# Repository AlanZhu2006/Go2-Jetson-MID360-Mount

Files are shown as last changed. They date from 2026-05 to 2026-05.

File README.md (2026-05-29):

# Unitree Go2 + Jetson Livox MID-360 Top Mount  
# 宇树 Unitree Go2 加装 Jetson 版本 Livox MID-360 顶部支架

[English](#english) | [中文](#中文)

---

## English

### Overview

This repository provides a 3D-printable top mounting bracket for installing a **Livox MID-360 LiDAR** on a **Unitree Go2 with an added Jetson module**.

Unlike many back-deck mounting solutions, this design places the MID-360 **above the Go2 head / front-top area**. The purpose is to keep the LiDAR dome higher and more exposed, so that the sensor has a better surrounding view and is less blocked by the Go2 body, Jetson module, power cables, USB/Ethernet adapters, and other onboard devices.

This mount is designed for robotics experiments such as:

- LiDAR SLAM / LIO
- Go2 navigation and localization
- MID-360 data collection
- Jetson onboard perception experiments
- real-robot deployment where the original rear/top deck is already occupied by Jetson or other electronics

> This is a community/open-source mechanical adapter, not an official Unitree or Livox product. Please verify hole positions, screw length, clearance, and mechanical strength on your own robot before operation.

---

### Images

#### Full installation overview

Place the full robot photo here:

```markdown
![Full installation overview](media/go2_mid360_jetson_overview.jpg)
```

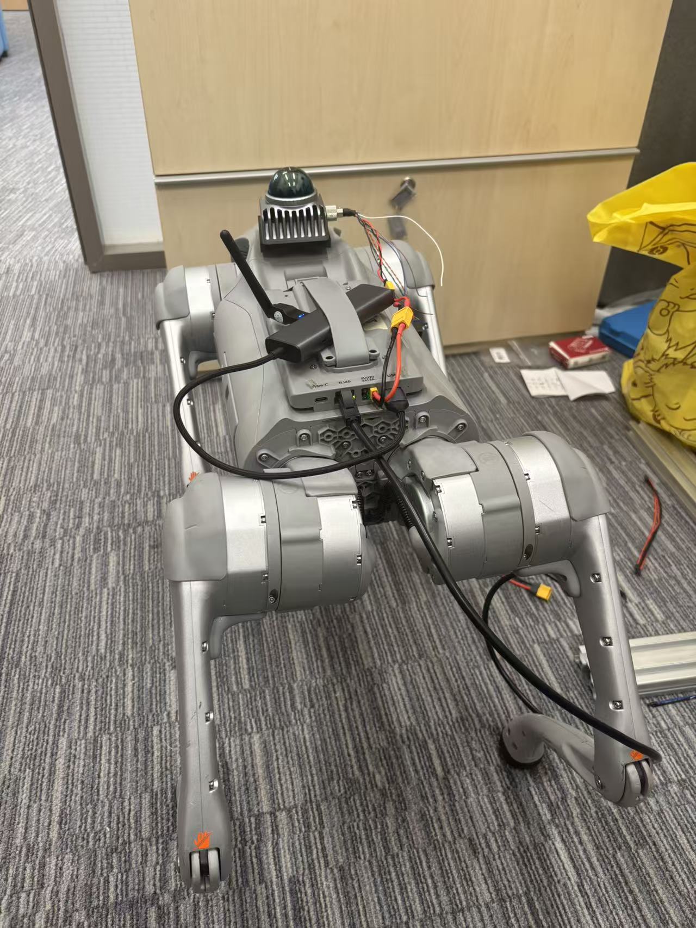
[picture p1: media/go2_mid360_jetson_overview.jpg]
Full installation overview


#### CAD / hole-layout preview

Place the top-down CAD / hole-layout preview here:

```markdown
![Top-down CAD preview](media/topdown_slot_preview.png)
```

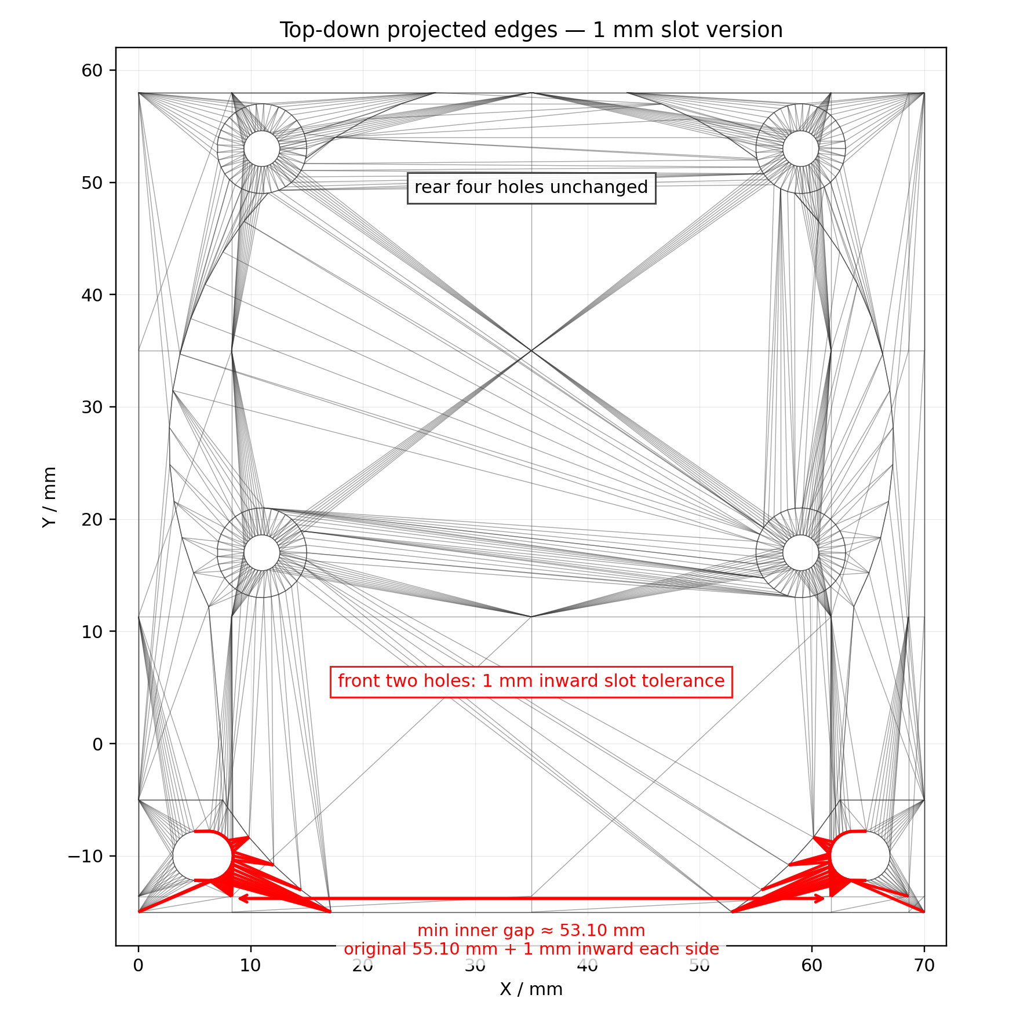
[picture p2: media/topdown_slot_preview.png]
Top-down CAD preview


---

### Design motivation

Many MID-360 mounts for Unitree Go2 assume that the top/back platform is mostly clean. In the **Go2 EDU / Jetson-added configuration**, however, the upper body area is often already occupied by:

- a Jetson module
- power cables
- USB/Ethernet adapters
- XT connectors
- network modules or additional electronics

A rear-mounted MID-360 may therefore be partially blocked by the Jetson or cable bundle. This design moves the sensor to the **front-top/head area**, with the goal of preserving a more useful LiDAR field of view for SLAM, localization, and navigation.

---

### Mechanical design

The bracket follows a simple mechanical logic:

1. **Four MID-360 mounting holes**  
   The four main holes on the upper mounting plate correspond to the MID-360 mounting pattern. They are intended for M3 screws used to fasten the MID-360 to the printed bracket.

2. **Two Go2 front mounting holes**  
   The two front holes correspond to the existing threaded holes on the top/front area of the Unitree Go2 body. These holes are used to fix the bracket to the robot.

3. **1 mm inward slot tolerance**  
   The two Go2-side front holes are designed as short inward slots instead of perfect circular holes. Each side has about 1 mm inward tolerance. This compensates for real measurement error, 3D-printing shrinkage, and small manufacturing differences between robots.

4. **Rear four holes unchanged**  
   The four MID-360 mounting holes should remain unchanged unless you intentionally redesign the LiDAR-side mounting pattern.

5. **Top-mounted sensor placement**  
   The MID-360 is placed above the Go2 head/front-top region to improve visibility and reduce occlusion from the Jetson platform and cables.

---

### Important dimensions and hole logic

| Feature | Description |
|---|---|
| LiDAR-side mounting holes | 4 × M3 clearance holes for Livox MID-360 mounting |
| Robot-side mounting holes | 2 × M3 clearance / short-slot holes for Go2 threaded mounting points |
| Front-hole measured reference | 55.10 mm inner-side reference distance measured on the Go2 body |
| Slot tolerance | 1 mm inward slot tolerance on each of the two front holes |
| Slot purpose | Compensates for printing tolerance and real robot measurement error |
| Rear four holes | Kept unchanged for the MID-360 mounting pattern |

> The 55.10 mm value refers to the measured inner-side distance from the real Go2 body, not the screw center-to-center distance. Do not reinterpret it as center pitch.

---

### Repository structure

Suggested structure:

```text
unitree-go2-jetson-mid360-top-mount/
├── README.md
├── LICENSE
├── cad/
│   └── unitree_go2_jetson_mid360_top_mount.stl
└── media/
    ├── go2_mid360_jetson_overview.jpg
    └── topdown_slot_preview.png
```

| File | Description |
|---|---|
| `cad/unitree_go2_jetson_mid360_top_mount.stl` | Printable STL model of the bracket |
| `media/go2_mid360_jetson_overview.jpg` | Full installation overview photo |
| `media/topdown_slot_preview.png` | Top-down preview showing the hole layout and 1 mm slot tolerance |
| `README.md` | Project documentation |
| `LICENSE` | Open-source license file |

---

### Required hardware

| Part | Quantity | Notes |
|---|---:|---|
| Livox MID-360 | 1 | LiDAR sensor |
| Unitree Go2 with Jetson module | 1 | Target robot platform |
| 3D-printed bracket | 1 | Print from the STL file |
| M3 screws for MID-360 | 4 | Length depends on bracket thickness and MID-360 thread depth |
| M3 screws for Go2 body | 2 | Use appropriate length for the Go2 threaded holes |
| M3 flat washers | 6 | Strongly recommended, especially for the two front slots |
| M3 spring washers or blue threadlocker | optional | Helps prevent loosening under vibration |
| Cable ties / cable clips | optional | For cable routing |

Screw notes:

- Do not use screws that are too long. They may bottom out or damage threads/components.
- For 3D-printed parts, flat washers are strongly recommended to distribute clamping force.
- For the two slotted front holes, washers are especially important because the slots rely on clamping force.

---

### 3D printing settings

Suggested settings:

| Setting | Recommended value |
|---|---|
| Material | PETG, PLA+, ABS, ASA, or PA-CF |
| Layer height | 0.20 mm |
| Walls / perimeters | 4 or more |
| Infill | 35–50% |
| Top/bottom layers | 5 or more |
| Supports | Enable if required by the selected print orientation |
| Brim | Recommended if warping occurs |
| Orientation | Keep the main mounting face flat when possible |

Material suggestions:

- **PETG**: recommended general-purpose option; tougher than standard PLA.
- **PLA+**: easy to print and acceptable for indoor testing, but may creep under long-term load or heat.
- **ASA / ABS**: better heat resistance, but needs a more controlled printing environment.
- **PA-CF / nylon-CF**: stronger and stiffer; recommended for more serious field tests if available.

---

### Assembly instructions

1. **Print the bracket**  
   Print the STL with enough walls and infill. Remove support material and clean the holes if necessary.

2. **Check screw fit before installation**  
   Test all holes with M3 screws before mounting the bracket on the robot. The Go2-side front holes are clearance/slot holes, not threaded holes.

3. **Mount the MID-360**  
   Align the MID-360 with the four LiDAR-side mounting holes. Use 4 × M3 screws to fasten the LiDAR to the bracket. Tighten gradually in a diagonal pattern.

4. **Mount the bracket on the Go2**  
   Align the two front slotted holes with the Go2 top/front threaded holes. Use 2 × M3 screws with flat washers. Adjust the position within the 1 mm slot tolerance, then tighten the screws.

5. **Route the cables**  
   Route the MID-360 power/data cable toward the Jetson or onboard computer. Avoid tight bending and avoid pulling on the LiDAR connector.

6. **Check clearance**  
   Make sure the mount does not collide with the Jetson module, Go2 body shell, head/front cover, cables, emergency stop, or other accessories.

7. **Static vibration check**  
   Before walking the robot, gently shake the mount by hand. If there is visible movement, tighten the screws, add washers, or improve the print quality.

8. **Low-speed walking test**  
   Start with standing or low-speed walking tests. Re-check all screws after the first few minutes of motion.

---

### Notes for SLAM / localization

After mechanical installation, the LiDAR frame still needs to be configured correctly in software.

Recommended checks:

- Verify the MID-360 coordinate-frame orientation.
- Measure or estimate the LiDAR-to-base transform.
- Publish the correct TF, for example `base_link -> mid360`.
- Make sure the MID-360 is approximately level when the Go2 is standing in its normal posture.
- Keep cables away from the LiDAR dome.
- Re-check extrinsics if the mount is removed and reinstalled.

For FAST-LIO, LIO-SAM, or other LIO systems, inaccurate extrinsics may cause drift, tilted maps, or unstable odometry even if the physical mount is rigid.

---

### Why the front holes use 1 mm slots

The Go2-side hole position is based on a real caliper measurement. Since 3D printing and robot shell tolerances can introduce small errors, perfectly circular holes may fail even when the CAD model looks correct.

This design uses a **1 mm inward slot tolerance** on each of the two front holes. Compared with a 2 mm slot, a 1 mm slot is more rigid and less likely to slip, while still providing useful assembly tolerance.

Use M3 flat washers to increase contact area and improve clamping stability.

---

### Safety warning

- Do not operate the Go2 at high speed before the mount is fully tested.
- Re-check all screws after walking tests.
- Use cable ties to prevent cables from entering joints or legs.
- Do not overtighten screws into plastic or threaded holes.
- Do not block the MID-360 dome.
- Protect the LiDAR from impact during falls or collisions.

---

### License

Recommended licenses:

- **MIT License**: simple and permissive.
- **CERN-OHL-S v2**: suitable for open-source hardware.
- **CC BY 4.0**: suitable if you mainly want attribution for CAD/images.

For a mechanical open-source hardware project, **CERN-OHL-S v2** or **MIT License** is recommended.

---

### Disclaimer

This project is provided as-is, without warranty. The author is not responsible for damage to robots, sensors, printed parts, or surrounding objects. Always verify mechanical fit, screw length, cable routing, and sensor safety before operating the robot.

---

## 中文

### 项目简介

本仓库提供一个可 3D 打印的 **Unitree Go2 加装 Jetson 版本 Livox MID-360 顶部安装支架**。

这个支架用于把 **Livox MID-360 激光雷达** 安装在 **宇树 Unitree Go2 头部 / 前上方区域**。相比安装在后背平台的方案，这个设计会让 MID-360 的圆顶更高、更靠前，从而减少 Go2 机身、Jetson 模块、电源线、USB / 网口转接器和其他设备对雷达视野的遮挡。

适用场景包括：

- 激光雷达 SLAM / LIO
- Go2 实机导航与定位
- MID-360 数据采集
- Jetson 机载感知实验
- 后背平台已经被 Jetson 或其他电子设备占用的 Go2 改装方案

> 这是一个社区开源机械适配件，不是 Unitree 或 Livox 官方产品。实机运行前请务必检查孔位、螺丝长度、安装强度、空间干涉和线缆安全。

---

### 图片展示

#### 完整安装效果图

在这里插入完整全貌图：

```markdown
![完整安装效果图](media/go2_mid360_jetson_overview.jpg)
```

完整安装效果图

#### CAD / 孔位预览图

在这里插入顶视孔位预览图：

```markdown
![孔位预览图](media/topdown_slot_preview.png)
```

孔位预览图

---

### 设计动机

很多 Unitree Go2 的 MID-360 支架默认机身上方或后背平台比较干净。但在 **Go2 EDU / 加装 Jetson** 的配置下，机器人上方往往已经有：

- Jetson 模块
- 电源线
- USB / 网口转接器
- XT 接头
- 通信模块或其他电子设备

如果 MID-360 继续安装在后背或较低位置，雷达可能会被 Jetson、线缆或机身结构部分遮挡。因此本设计把 MID-360 移到 **Go2 头部上方 / 前上方**，目标不是单纯固定雷达，而是尽量保证 SLAM、定位和导航所需的雷达视野。

---

### 机械设计说明

支架的设计逻辑如下：

1. **四个 MID-360 安装孔**  
   上方安装板上的四个孔对应 MID-360 的安装参数，用于通过 M3 螺丝把 Livox MID-360 固定到 3D 打印支架上。

2. **前面两个 Go2 安装孔**  
   前面两个孔对应 Unitree Go2 头部上方 / 前上方的原有螺纹孔，用于把支架固定到 Go2 机身上。

3. **前两个孔做 1 mm 向内长圆槽容差**  
   这两个孔不是完全圆孔，而是短长圆槽。每个孔向中间额外留出约 1 mm 调整空间，用来补偿实物测量误差、3D 打印收缩和不同机器之间的小偏差。

4. **后面四个孔保持不变**  
   后面四个孔对应 MID-360 的安装孔位，不应该随意改动，除非你明确要修改雷达安装参数。

5. **安装在 Go2 头部上方以确保视野**  
   MID-360 放在 Go2 头部上方，减少 Jetson、线缆和机身后背平台对雷达视野的遮挡。

---

### 关键尺寸和孔位逻辑

| 项目 | 说明 |
|---|---|
| 雷达侧安装孔 | 4 × M3 过孔，对应 Livox MID-360 安装孔位 |
| 机器人侧安装孔 | 2 × M3 过孔 / 短长圆槽，对应 Go2 机身原有螺纹孔 |
| 前孔实测基准 | 55.10 mm 内侧参考距离，来自 Go2 实物卡尺测量 |
| 槽孔容差 | 两个前孔各自向内额外留 1 mm |
| 槽孔目的 | 补偿打印误差、测量误差和机身公差 |
| 后四孔 | 保持 MID-360 安装孔位不变 |

> 这里的 55.10 mm 指的是卡尺照片中测得的内侧参考距离，不是螺丝中心距。不要把它误解成 center-to-center pitch。

---

### 文件结构

建议仓库结构如下：

```text
unitree-go2-jetson-mid360-top-mount/
├── README.md
├── LICENSE
├── cad/
│   └── unitree_go2_jetson_mid360_top_mount.stl
└── media/
    ├── go2_mid360_jetson_overview.jpg
    └── topdown_slot_preview.png
```

| 文件 | 说明 |
|---|---|
| `cad/unitree_go2_jetson_mid360_top_mount.stl` | 可直接打印的支架 STL 文件 |
| `media/go2_mid360_jetson_overview.jpg` | 完整安装效果图 |
| `media/topdown_slot_preview.png` | 顶视孔位和 1 mm 槽孔预览图 |
| `README.md` | 项目说明文档 |
| `LICENSE` | 开源协议文件 |

---

### 所需硬件

| 零件 | 数量 | 说明 |
|---|---:|---|
| Livox MID-360 | 1 | 激光雷达 |
| 加装 Jetson 的 Unitree Go2 | 1 | 目标机器人平台 |
| 3D 打印支架 | 1 | 使用本仓库 STL 打印 |
| MID-360 固定用 M3 螺丝 | 4 | 长度取决于支架厚度和 MID-360 螺纹深度 |
| Go2 机身固定用 M3 螺丝 | 2 | 长度需适配 Go2 机身螺纹孔 |
| M3 平垫片 | 6 | 强烈建议使用，尤其是前两个槽孔 |
| M3 弹垫或蓝色螺纹胶 | 可选 | 用于防松 |
| 扎带 / 理线夹 | 可选 | 用于固定线缆 |

螺丝注意事项：

- 不要使用过长螺丝，避免顶到底或损坏内部结构。
- 3D 打印件建议配合平垫片使用，避免螺丝头直接压坏塑料。
- 前两个槽孔尤其建议加垫片，因为槽孔主要依靠螺丝夹紧力固定。

---

### 3D 打印建议

| 设置 | 推荐值 |
|---|---|
| 材料 | PETG、PLA+、ABS、ASA 或 PA-CF |
| 层高 | 0.20 mm |
| 壁厚 / 墙数 | 4 层或更多 |
| 填充率 | 35–50% |
| 顶/底层 | 5 层或更多 |
| 支撑 | 根据切片方向开启 |
| Brim 裙边 | 如果翘边，建议开启 |
| 打印方向 | 尽量让主要安装面平放在热床上 |

材料建议：

- **PETG**：综合推荐，韧性比普通 PLA 更好。
- **PLA+**：容易打印，适合室内测试，但长期受力或高温下可能蠕变。
- **ASA / ABS**：耐温更好，但需要更好的打印环境。
- **PA-CF / 尼龙碳纤**：强度和刚性更好，适合更严肃的实机测试。

---

### 安装步骤

1. **打印支架**  
   使用足够的墙数和填充率打印 STL。打印完成后清理支撑，并检查孔位是否通畅。

2. **测试螺丝能否穿过**  
   安装到机器人之前，先用 M3 螺丝测试所有孔位。Go2 侧前两个孔是过孔 / 槽孔，不是螺纹孔。

3. **安装 MID-360**  
   将 MID-360 对准支架上的四个雷达安装孔。使用 4 颗 M3 螺丝固定，建议对角逐步拧紧。

4. **安装到 Go2 机身**  
   将前两个槽孔对准 Go2 头部上方的 M3 螺纹孔。使用 2 颗 M3 螺丝并配合平垫片固定。根据 1 mm 槽孔余量微调位置后拧紧。

5. **整理线缆**  
   将 MID-360 的电源和数据线引到 Jetson 或机载计算设备。避免线缆过度弯折，也不要让线缆拉扯雷达接口。

6. **检查空间干涉**  
   确认支架不会和 Jetson 模块、Go2 机身外壳、头部 / 前盖、线缆、急停按钮或其他附件发生干涉。

7. **静态晃动测试**  
   在机器人行走前，用手轻轻晃动支架。如果有明显松动，需要重新拧紧、加垫片或改善打印质量。

8. **低速行走测试**  
   先进行站立或低速行走测试。运动几分钟后重新检查所有螺丝是否松动。

---

### SLAM / 定位使用注意事项

机械安装完成后，软件中仍然需要正确配置雷达坐标系。

建议检查：

- 确认 MID-360 坐标轴方向。
- 测量或估计 LiDAR 到 `base_link` 的外参。
- 发布正确 TF，例如 `base_link -> mid360`。
- 确保 Go2 正常站立时 MID-360 尽量水平。
- 避免线缆挡住雷达圆顶。
- 如果支架拆装过，建议重新检查外参。

对于 FAST-LIO、LIO-SAM 或其他 LIO 系统，即使机械安装很牢，如果外参不准确，也可能导致地图倾斜、轨迹漂移或里程计不稳定。

---

### 为什么前两个孔使用 1 mm 长圆槽

前两个孔的位置来自实物卡尺测量。由于 3D 打印收缩、孔洞误差、机身曲面和不同 Go2 个体之间的细微差异，完全圆孔很容易出现 CAD 正确但实物装不上的情况。

所以本设计在前两个 Go2 固定孔上做了 **1 mm 向内长圆槽容差**。相比 2 mm 长槽，1 mm 槽更稳，不容易滑动；同时又比纯圆孔更容易装配。

安装时建议配合 M3 平垫片，增加压紧面积，提高固定稳定性。

---

### 安全提醒

- 支架没有充分测试前，不要让 Go2 高速运动。
- 每次行走测试后检查螺丝是否松动。
- 用扎带固定线缆，避免线缆卷入关节或腿部。
- 不要过度拧紧螺丝，避免压裂 3D 打印件或损坏螺纹。
- 不要遮挡 MID-360 圆顶。
- 跌倒或碰撞时注意保护雷达。

---

### 开源协议建议

可以选择以下协议发布：

- **MIT License**：简单宽松，适合快速开源。
- **CERN-OHL-S v2**：更适合开源硬件项目。
- **CC BY 4.0**：适合希望别人使用时保留署名的 CAD / 图片项目。

如果这是一个机械开源硬件项目，推荐使用 **CERN-OHL-S v2** 或 **MIT License**。

---

### 免责声明

本项目按原样提供，不提供任何形式的保证。作者不对机器人、传感器、打印件或周围物体的损坏负责。实机运行前，请自行确认孔位、螺丝长度、安装强度、线缆走线和传感器安全。

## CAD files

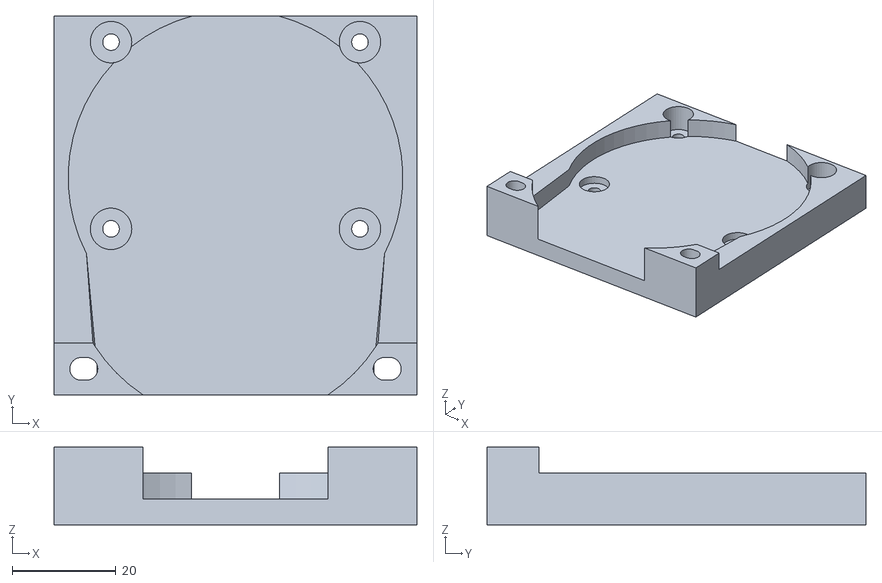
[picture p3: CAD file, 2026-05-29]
cad/unitree_go2_jetson_mid360_top_mount.stl
70.0 x 73.0 x 15.0
